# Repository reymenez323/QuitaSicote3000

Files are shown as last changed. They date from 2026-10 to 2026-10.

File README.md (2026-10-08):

# QuitaSicote3000

Equipo doméstico que elimina el mal olor del calzado con aire caliente forzado. Se controla sólo desde la pantalla táctil y tiene una capa de seguridad independiente (SIS).

Repositorio: https://github.com/reymenez323/QuitaSicote3000

**Empieza por [docs/PLAN-MAESTRO.md](docs/PLAN-MAESTRO.md)**: plan completo de electrónica y firmware.

**¿Vas a armar el equipo?** Sigue la [guía de conexión paso a paso](docs/guia-de-conexion/README.md) (incluye el diagrama de Fritzing en alta resolución).

> **Regla de máxima prioridad**: el **control** es el **ESP32 DevKit V1 de control** y el **SIS** es el **ESP32 Dev Kit**, estrictamente en todo el proyecto ([ADR-0012](docs/decisiones/ADR-0012-regla-mega-control-nano-sis.md)).
> **Hardware**: sólo módulos y dispositivos; sin optoacopladores, convertidores de nivel ni fusibles ([ADR-0013](docs/decisiones/ADR-0013-solo-modulos-y-dispositivos.md)).

## Nodos

| Nodo | Placa | Rol | Carpeta |
|---|---|---|---|
| Control | ESP32 DevKit V1 de control | Ciclo, sensores, SSR del PTC y ventiladores | [firmware/control](firmware/control/) |
| SIS | ESP32 Dev Kit | Seguridad: puede cortar el calentador sin pedir permiso | [firmware/sis](firmware/sis/) |
| HMI | ESP32-32E con pantalla 3.2" | Interfaz táctil; sólo comunicación | [firmware/hmi](firmware/hmi/) |

Los tres trabajan a 3,3 V y se conectan entre sí directamente.

## Estructura

```
QuitaSicote3000/
├─ docs/
│  ├─ PLAN-MAESTRO.md            Plan completo de implementación (electrónica + firmware). Empieza aquí
│  ├─ pinout/                    Pinout de cada controlador: control-esp32.md, sis-esp32.md, esp32-hmi.md
│  ├─ guia-de-conexion/          Guía paso a paso para conectar todo (con el diagrama de Fritzing por zonas)
│  ├─ requisitos.md              Qué debe hacer el sistema y parámetros provisionales
│  ├─ arquitectura.md            Nodos, reparto de responsabilidades, principios
│  ├─ maquina-de-estados.md      Ciclo de tratamiento (control)
│  ├─ perfiles-de-tratamiento.md Calzado × intensidad × duración
│  ├─ comunicacion.md            Enlaces UART y mensajes
│  ├─ seguridad-sis.md           Funciones de seguridad y su validación
│  └─ decisiones/                ADRs y decisiones abiertas
├─ hardware/
│  └─ fritzing/                  Diagrama de conexiones (.fzz editable y PNG de alta resolución)
└─ firmware/
   ├─ control/                   Proyecto PlatformIO del ESP32 DevKit V1 de control
   ├─ sis/                       Proyecto PlatformIO del ESP32 Dev Kit
   ├─ hmi/                       Proyecto PlatformIO del ESP32-32E (LVGL) + PLAN.md
   └─ compartido/qs_protocol.h   Contrato común entre nodos
```

## Convenciones

- Documentación y comentarios en español; identificadores de código en inglés.
- PlatformIO con Arduino-ESP32, un proyecto por nodo.
- Decisiones de diseño como ADR en [docs/decisiones](docs/decisiones/README.md).

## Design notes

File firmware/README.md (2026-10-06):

# Firmware

> Regla de máxima prioridad: **el control y el SIS corren en dos ESP32 DevKit V1 distintos** ([ADR-0012](../docs/decisiones/ADR-0012-regla-mega-control-nano-sis.md)).

Tres proyectos PlatformIO (framework Arduino-ESP32). **Toda la lógica corre en tareas de FreeRTOS** y cada proyecto cabe en muy pocos archivos, pensados para leerse de arriba abajo.

```
firmware/
├─ compartido/
│  └─ qs_protocol.h     El "contrato": identificadores, mensajes y tramas. Lo incluyen los tres.
├─ sis/                 ESP32 DevKit V1 n.º 2 — sólo seguridad
│  └─ src/  config.h (pines y umbrales) · main.cpp
├─ control/             ESP32 DevKit V1 n.º 1 — sólo control
│  └─ src/  config.h (pines, parámetros y perfiles) · sensors.h · main.cpp
└─ hmi/                 ESP32-32E con pantalla 3.2" — sólo interfaz
   ├─ include/lv_conf.h (configuración de LVGL)
   └─ src/  display.h (pines y pantalla) · ui.h · ui.cpp (pantallas) · main.cpp
```

## Tareas de cada nodo

| Nodo | Tarea | Periodo | Qué hace |
|---|---|---|---|
| SIS | `taskSafety` | 10 ms | Puerta → funciones de seguridad → relés RL1, RL3, RL4. Vigilada por el watchdog (1 s) |
| SIS | `taskLink` | 10 ms | Habla con el control; guarda en memoria no volátil |
| Control | `taskCycle` | 10 ms | Puerta → máquina de estados → SSR1 y ventiladores. Vigilada por el watchdog (2 s) |
| Control | `taskSensors` | 250 ms | TC1 y TC2 alternados; cada segundo, humedad y olor |
| Control | `taskSisLink` | 10 ms | Recibe `HB_SIS`; envía `HB_CTRL`, rearmes y servicio |
| Control | `taskHmiLink` | 10 ms | Recibe las solicitudes de la pantalla; envía `STATUS` |
| Control | `taskConsole` | 100 ms | Comandos por USB y registro CSV |
| HMI | `taskUi` | 5 ms | LVGL: dibuja y lee el táctil |
| HMI | `taskLink` | 10 ms | Recibe `STATUS`; envía el latido y las solicitudes |

En cada nodo, las tareas comparten unas pocas variables globales protegidas por **un mutex** (clase `Lock`). Donde una tarea le encarga algo a otra se usa **una cola** (avisos del SIS, botones del HMI).

## Compilar y cargar

Desde la carpeta de cada proyecto (`sis`, `control` o `hmi`):

```bash
pio run -t upload
```

```bash
pio device monitor
```

Si `pio` no está en el PATH: `%USERPROFILE%\.platformio\penv\Scripts\pio.exe`.

Las dos placas DevKit V1 son iguales: **etiquétalas** ("CONTROL" y "SIS") y carga en cada una su firmware.

## Estado

Los tres proyectos compilan. **Nada se ha probado todavía en hardware.** No hay pruebas automáticas: la validación es en banco, siguiendo [docs/seguridad-sis.md](../docs/seguridad-sis.md#validación) (inyección de fallas V-01…V-13). Repetirla tras cada cambio del SIS.

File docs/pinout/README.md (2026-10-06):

# Pinout por controlador

> Regla de máxima prioridad: **control y SIS en dos ESP32 DevKit V1 distintos** ([ADR-0012](../decisiones/ADR-0012-regla-mega-control-nano-sis.md)). Sólo módulos y dispositivos ([ADR-0013](../decisiones/ADR-0013-solo-modulos-y-dispositivos.md)).

Un documento independiente por cada controlador:

| Controlador | Nodo | Qué maneja | Documento |
|---|---|---|---|
| ESP32 DevKit V1 n.º 1 | **Control** | SSR1 (PTC), SSR2 (FAN_C), RL2 (apagar FAN_P), TC1, TC2, SHT31, SGP40, puerta | [control-esp32.md](control-esp32.md) |
| ESP32 DevKit V1 n.º 2 | **SIS** | RL1 (permiso del PTC), RL3 (veto del apagado de FAN_P), RL4 (forzado de FAN_C), puerta | [sis-esp32.md](sis-esp32.md) |
| ESP32-32E (pantalla 3.2") | HMI | Nada del proceso: pantalla, táctil y enlace | [esp32-hmi.md](esp32-hmi.md) |

Los tres trabajan a **3,3 V**: todos los cables entre ellos son **directos**. Contexto eléctrico completo: [PLAN-MAESTRO §5](../PLAN-MAESTRO.md#5-electrónica).
Las dos placas son del mismo modelo: **etiquetarlas** ("CONTROL" y "SIS"). Usan los mismos números de pin para la puerta, las salidas, el SPI y el UART entre ellas.

## Cables entre controladores

| Señal | Desde | Hacia |
|---|---|---|
| UART control → SIS | Control GPIO17 (TX2) | SIS GPIO16 (RX2) |
| UART SIS → control | SIS GPIO17 (TX2) | Control GPIO16 (RX2) |
| UART control → HMI | Control GPIO4 (TX1) | HMI IO32 (RX2) |
| UART HMI → control | HMI IO25 (TX2) | Control GPIO35 (RX1) |
| Puerta NA (compartida) | SW1.NA | Control GPIO32 y SIS GPIO32 |
| Puerta NC (compartida) | SW1.NC | Control GPIO33 y SIS GPIO33 |
| GND común | GND de las tres placas | Estrella de tierra |

## Combinación por contactos (no hay cable entre controladores)

| Ventilador | Control | SIS | Combinación |
|---|---|---|---|
| FAN_P | RL2 (GPIO27) | RL3 (GPIO26) | Contactos NC en paralelo: se apaga sólo si ambos están energizados |
| FAN_C | SSR2 (GPIO26) | RL4 (GPIO27) | Contacto NA en paralelo con SSR2: se enciende si cualquiera lo activa |

## Polaridades que el firmware debe respetar

| Señal | Controlador | ALTO significa |
|---|---|---|
| `PIN_SSR1` | Control | Calentar |
| `PIN_FAN_C` | Control | Encender ventilador de circulación |
| `PIN_FAN_P_OFF` | Control | **Pedir apagado** del ventilador del PTC |
| `PIN_PTC_PERMIT` | SIS | PTC permitido (RL1 cerrado) |
| `PIN_FAN_P_OFF_PERMIT` | SIS | **Permitir** apagar el ventilador del PTC |
| `PIN_FAN_C_FORCE` | SIS | Forzar ventilador de circulación |
| Puerta NA / NC | Control y SIS | Contacto abierto. Puerta cerrada = NA BAJO + NC ALTO |
| LED RGB del HMI | HMI | **Apagado** (ánodo común) |

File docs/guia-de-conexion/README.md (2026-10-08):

# Guía de conexión

Sigue los pasos **en orden**, con la fuente **desenchufada**. Marca cada ☐ al terminar.
Si la guía y los [pinout](../pinout/README.md) no coinciden, mandan los pinout.

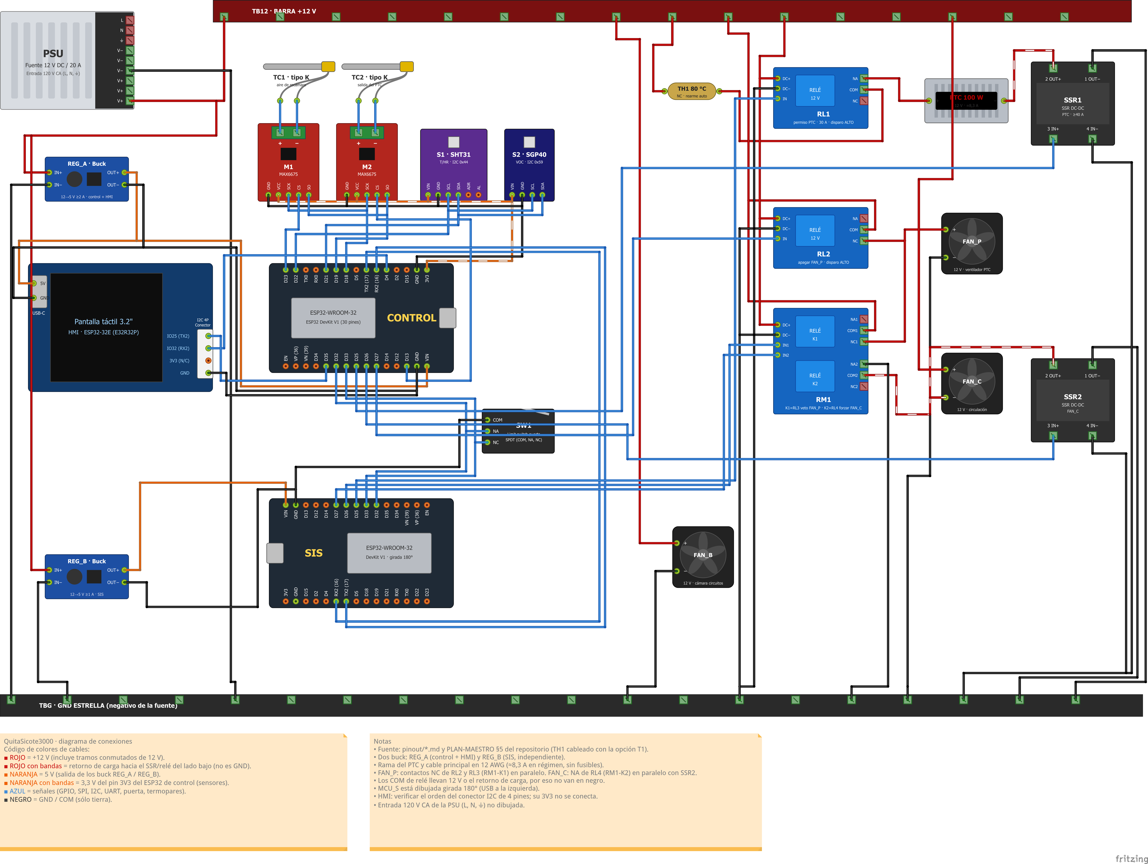
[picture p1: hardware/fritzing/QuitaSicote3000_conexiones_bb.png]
Diagrama completo


Diagrama completo en alta resolución (7740 × 5829 px): [PNG](../../hardware/fritzing/QuitaSicote3000_conexiones_bb.png) · [Fritzing editable](../../hardware/fritzing/QuitaSicote3000_conexiones.fzz).
Pinouts de las placas y módulos: [ver tablas](#pinouts).
Recortes a escala completa: [1 Fuente](zona1-fuente-y-reguladores.png) · [2 Control y sensores](zona2-control-y-sensores.png) · [3 SIS y puerta](zona3-sis-y-puerta.png) · [4 Cargas](zona4-cargas.png).

| Color de cable | Significa |
|---|---|
| 🟥 Rojo | +12 V |
| 🟥 Rojo con bandas | Retorno de carga (lleva 12 V, **no** es tierra) |
| 🟧 Naranja | 5 V |
| 🟦 Azul | Señal de 3,3 V |
| ⬛ Negro | GND |

---

## ⚠️ Antes de empezar

- ☐ **Etiqueta las dos placas ESP32 como CONTROL y SIS.** Son idénticas; si se confunden, el equipo no es seguro.
- **Nunca pongas 12 V ni 5 V en un pin de señal (azul).** Destruye la placa.
- **Sin fusibles:** cable de **12 AWG** en la rama del calefactor; cables finos cortos y sujetos.
- Los **120 V de la fuente** no están en el diagrama: se conectan **al final**, con bornes tapados. Sin experiencia, que lo haga un electricista.
- **No conectes USB a una placa mientras su regulador de 5 V esté conectado.**
- Necesitas un **multímetro** y los firmwares cargados ([firmware/](../../firmware/README.md)): cárgalos **antes** de cablear, cada placa sola por USB.
- En el diagrama el SIS está **girado 180°**: guíate por la etiqueta del pin (`D25`, `GND`…), no por la posición.

---

## Paso 1 — Barras de 12 V y GND  📷 [zona 1](zona1-fuente-y-reguladores.png)

| Desde | Hacia | Cable |
|---|---|---|
| Fuente `V+` | Barra **TB12** | Rojo, 12 AWG |
| Fuente `V−` | Barra **TBG** (GND) | Negro, 12 AWG |

☐ Multímetro en continuidad: TB12 ↔ TBG **no** debe pitar.

## Paso 2 — Reguladores de 5 V  📷 [zona 1](zona1-fuente-y-reguladores.png)

| Desde | Hacia |
|---|---|
| TB12 | REG_A `IN+` y REG_B `IN+` |
| TBG | REG_A `IN−` y REG_B `IN−` (un cable cada uno) |

☐ Con la fuente encendida y **nada** en las salidas, gira el tornillo de cada regulador hasta medir **5,0–5,1 V** entre `OUT+` y `OUT−`. Apaga y desenchufa.

## Paso 3 — Sensores de CONTROL  📷 [zona 2](zona2-control-y-sensores.png)

| Desde | Hacia | Cable |
|---|---|---|
| CONTROL `3V3` | M1 `VCC`, M2 `VCC`, S1 `VIN`, S2 `VIN` | Naranja |
| CONTROL `GND` | M1 `GND`, M2 `GND`, S1 `GND`, S2 `GND` | Negro |
| CONTROL `D18` | M1 `SCK` y M2 `SCK` | Azul |
| CONTROL `D19` | M1 `SO` y M2 `SO` | Azul |
| CONTROL `D23` | M1 `CS` | Azul |
| CONTROL `D13` | M2 `CS` | Azul |
| CONTROL `D21` | S1 `SDA` y S2 `SDA` | Azul |
| CONTROL `D22` | S1 `SCL` y S2 `SCL` | Azul |
| Termopar TC1 | M1 `+` / `−` | |
| Termopar TC2 | M2 `+` / `−` | |

- Sensores a **3,3 V, no a 5 V**. `ADR` y `AL` del SHT31: sin conectar.
- Termopar: hilo positivo a `+` (en ANSI tipo K suele ser el amarillo). Si al calentar la lectura baja, están invertidos.

## Paso 4 — Puerta (SW1)  📷 [zona 3](zona3-sis-y-puerta.png)

| Desde | Hacia |
|---|---|
| SW1 `COM` | TBG |
| SW1 `NA` | CONTROL `D32` **y** SIS `D32` |
| SW1 `NC` | CONTROL `D33` **y** SIS `D33` |

El cable de `NA` (y el de `NC`) se divide en dos: uno a cada placa. Sin resistencias externas.

## Paso 5 — Alimentación de las placas

| Desde | Hacia | Cable |
|---|---|---|
| REG_A `OUT+` | CONTROL `VIN` | Naranja |
| REG_A `OUT−` | CONTROL `GND` | Negro |
| REG_A `OUT+` | Pantalla USB-C `5V` | Naranja |
| REG_A `OUT−` | Pantalla USB-C `GND` | Negro |
| REG_B `OUT+` | SIS `VIN` | Naranja |
| REG_B `OUT−` | SIS `GND` | Negro |

## Paso 6 — Enlaces entre placas  📷 [zona 1](zona1-fuente-y-reguladores.png) · [2](zona2-control-y-sensores.png) · [3](zona3-sis-y-puerta.png)

**TX va al RX del otro** (cruzados). Todos los GND de las placas, juntos.

| Desde | Hacia |
|---|---|
| CONTROL `D17` (TX2) | SIS `D16` (RX2) |
| SIS `D17` (TX2) | CONTROL `D16` (RX2) |
| CONTROL `D4` | Pantalla `IO32` |
| Pantalla `IO25` | CONTROL `D35` |
| Pantalla `GND` | CONTROL `GND` |

Los pines `IO25`, `IO32` y `GND` están en el **conector pequeño de 4 pines "I2C"** de la pantalla. **No conectes su `3V3`.**
☐ Identifica cada pin de ese conector con el multímetro antes de conectar (el orden no está confirmado).

## Paso 7 — Módulos de relé y SSR: 12 V y señales  📷 [zona 4](zona4-cargas.png)

| Módulo | Conexión | Hacia |
|---|---|---|
| RL1, RL2, RM1 | `DC+` | TB12 |
| RL1, RL2, RM1 | `DC−` | TBG |
| SSR1 | `4 IN−` | TBG |
| SSR2 | `4 IN−` | TBG |
| SSR1 | `3 IN+` | CONTROL `D25` |
| SSR2 | `3 IN+` | CONTROL `D26` |
| RL2 | `IN` | CONTROL `D27` |
| RL1 | `IN` | SIS `D25` |
| RM1 | `IN1` | SIS `D26` |
| RM1 | `IN2` | SIS `D27` |

RM1 con bobina de 12 V: confírmalo en la etiqueta de tu módulo (algunos son de 5 V).

## Paso 8 — Ventiladores  📷 [zona 4](zona4-cargas.png)

| Desde | Hacia | Cable |
|---|---|---|
| TB12 | FAN_B `+` | Rojo |
| FAN_B `−` | TBG | Negro |
| TB12 | RL2 `COM` | Rojo |
| TB12 | RM1 `COM1` | Rojo |
| RL2 `NC` | FAN_P `+` | Rojo |
| RM1 `NC1` | FAN_P `+` (mismo punto) | Rojo |
| FAN_P `−` | TBG | Negro |
| TB12 | FAN_C `+` | Rojo |
| FAN_C `−` | SSR2 `2 OUT+` | Rojo con bandas |
| FAN_C `−` | RM1 `COM2` (mismo punto) | Rojo con bandas |
| SSR2 `1 OUT−` | TBG | Negro |
| RM1 `NA2` | TBG | Negro |

## Paso 9 — Calefactor PTC  📷 [zona 4](zona4-cargas.png)

> ⚠️ **Último paso. Todo en 12 AWG con terminales bien apretados** (≈ 8,3 A). Para las primeras pruebas **usa una lámpara de 12 V / 21 W en lugar del PTC.**

`TB12 → TH1 → RL1 (COM→NA) → PTC → SSR1 → TBG`

| Desde | Hacia |
|---|---|
| TB12 | TH1 (un cable) |
| TH1 (otro cable) | RL1 `COM` |
| RL1 `NA` | PTC `+` (o lámpara) |
| PTC `−` (o lámpara) | SSR1 `2 OUT+` |
| SSR1 `1 OUT−` | TBG |

`RL1 NC` queda sin conectar. TH1 va en el aire caliente, **sin tocar las aletas** del PTC. SSR1 con disipador.

---

## Pinouts

Todos los pines de señal son de **3,3 V**. "Etiqueta" es lo que está impreso en la placa. Detalle completo: [control](../pinout/control-esp32.md) · [SIS](../pinout/sis-esp32.md) · [pantalla](../pinout/esp32-hmi.md).

### CONTROL (ESP32 DevKit V1)

| Etiqueta | GPIO | Dir. | Señal | Va a | ALTO / BAJO significa |
|---|---|---|---|---|---|
| `D25` | 25 | Salida | Calentar | SSR1 `3 IN+` | ALTO = calentar |
| `D26` | 26 | Salida | Ventilador de circulación | SSR2 `3 IN+` | ALTO = encender |
| `D27` | 27 | Salida | Pedir apagar FAN_P | RL2 `IN` | ALTO = pedir apagado |
| `D32` | 32 | Entrada | Puerta NA | SW1 `NA` (y SIS `D32`) | BAJO = contacto cerrado |
| `D33` | 33 | Entrada | Puerta NC | SW1 `NC` (y SIS `D33`) | BAJO = contacto cerrado |
| `D21` | 21 | E/S | I2C SDA | S1 `SDA`, S2 `SDA` | — |
| `D22` | 22 | Salida | I2C SCL | S1 `SCL`, S2 `SCL` | — |
| `D18` | 18 | Salida | SPI SCK | M1 `SCK`, M2 `SCK` | — |
| `D19` | 19 | Entrada | SPI MISO | M1 `SO`, M2 `SO` | — |
| `D23` | 23 | Salida | CS de TC1 | M1 `CS` | BAJO = seleccionado |
| `D13` | 13 | Salida | CS de TC2 | M2 `CS` | BAJO = seleccionado |
| `D17` (`TX2`) | 17 | Salida | Datos → SIS | SIS `D16` | UART 115200 |
| `D16` (`RX2`) | 16 | Entrada | Datos ← SIS | SIS `D17` | UART 115200 |
| `D4` | 4 | Salida | Datos → pantalla | Pantalla `IO32` | UART 115200 |
| `D35` | 35 | Entrada | Datos ← pantalla | Pantalla `IO25` | UART 115200 |
| `3V3` | — | Salida | 3,3 V | M1, M2, S1, S2 (`VCC`/`VIN`) | — |
| `VIN` | — | Entrada | 5 V | REG_A `OUT+` | — |
| `GND` | — | — | Tierra | TBG y todos los GND | — |

No uses otros pines: `0, 2, 5, 12, 14, 15` son de arranque y `1, 3, 6–11` son de USB y memoria.

### SIS (ESP32 DevKit V1)

| Etiqueta | GPIO | Dir. | Señal | Va a | ALTO / BAJO significa |
|---|---|---|---|---|---|
| `D25` | 25 | Salida | Permiso para calentar | RL1 `IN` | ALTO = permitido |
| `D26` | 26 | Salida | Permitir apagar FAN_P | RM1 `IN1` (RL3) | ALTO = se permite apagar |
| `D27` | 27 | Salida | Forzar FAN_C | RM1 `IN2` (RL4) | ALTO = forzar encendido |
| `D32` | 32 | Entrada | Puerta NA | SW1 `NA` (y CONTROL `D32`) | BAJO = contacto cerrado |
| `D33` | 33 | Entrada | Puerta NC | SW1 `NC` (y CONTROL `D33`) | BAJO = contacto cerrado |
| `D17` (`TX2`) | 17 | Salida | Datos → CONTROL | CONTROL `D16` | UART 115200 |
| `D16` (`RX2`) | 16 | Entrada | Datos ← CONTROL | CONTROL `D17` | UART 115200 |
| `VIN` | — | Entrada | 5 V | REG_B `OUT+` | — |
| `GND` | — | — | Tierra | TBG | — |

El SIS no tiene sensores ni termopares. Pines libres: `13, 18, 19, 21, 22, 23` (no conectar nada).

### Pantalla HMI (ESP32-32E)

Solo se usan estas conexiones externas; el resto de la placa ya viene cableado.

| Conector | Pin | Dir. | Señal | Va a |
|---|---|---|---|---|
| I2C (4 pines, 1,25 mm) | `IO25` | Salida | Datos → CONTROL (UART2 TX) | CONTROL `D35` |
| I2C (4 pines, 1,25 mm) | `IO32` | Entrada | Datos ← CONTROL (UART2 RX) | CONTROL `D4` |
| I2C (4 pines, 1,25 mm) | `GND` | — | Tierra | CONTROL `GND` |
| I2C (4 pines, 1,25 mm) | `3V3` | — | **No conectar** | — |
| USB-C | `5V` | Entrada | Alimentación | REG_A `OUT+` |
| USB-C | `GND` | — | Tierra | REG_A `OUT−` |

### Módulos (terminales)

| Módulo | Terminales y a dónde van |
|---|---|
| **M1 / M2** (MAX6675) | `VCC` ← 3V3 · `GND` · `SCK` ← D18 · `SO` → D19 · `CS` ← D23 (M1) o D13 (M2) · `+`/`−` ← termopar |
| **S1** (SHT31) | `VIN` ← 3V3 · `GND` · `SDA` ← D21 · `SCL` ← D22 · `ADR`, `AL` sin conectar |
| **S2** (SGP40) | `VIN` ← 3V3 · `GND` · `SDA` ← D21 · `SCL` ← D22 |
| **SW1** | `COM` → GND · `NA` → D32 (ambas placas) · `NC` → D33 (ambas placas) |
| **RL1** (30 A) | `DC+` ← 12 V · `DC−` → GND · `IN` ← SIS D25 · `COM` ← TH1 · `NA` → PTC `+` · `NC` sin conectar |
| **RL2** | `DC+` ← 12 V · `DC−` → GND · `IN` ← CONTROL D27 · `COM` ← 12 V · `NC` → FAN_P `+` · `NA` sin conectar |
| **RM1** (2 relés) | `DC+` ← 12 V · `DC−` → GND · `IN1` ← SIS D26 · `IN2` ← SIS D27 · `COM1` ← 12 V · `NC1` → FAN_P `+` · `COM2` ↔ FAN_C `−` · `NA2` → GND · `NA1`, `NC2` sin conectar |
| **SSR1** | `3 IN+` ← CONTROL D25 · `4 IN−` → GND · `2 OUT+` ← PTC `−` · `1 OUT−` → GND |
| **SSR2** | `3 IN+` ← CONTROL D26 · `4 IN−` → GND · `2 OUT+` ← FAN_C `−` · `1 OUT−` → GND |
| **REG_A / REG_B** | `IN+` ← 12 V · `IN−` → GND · `OUT+` → 5 V a su placa · `OUT−` → GND de su placa |

---

## Revisión (fuente desenchufada)

☐ TB12 ↔ TBG: **no** pita.
☐ `3V3` ↔ `GND` de CONTROL: **no** pita.
☐ Salidas `OUT+` ↔ `OUT−` de REG_A y REG_B: **no** pita.
☐ `D25`/`D26`/`D27` de CONTROL y SIS ↔ TB12: **no** pita.
☐ Todos los GND ↔ TBG: **sí** pita.
☐ Terminales gruesos apretados (tira de cada cable).

## Primer encendido

1. ☐ **Solo fuente y reguladores** (sin cables a las placas): TB12 = 12 V, reguladores = 5,0–5,1 V. FAN_B y FAN_P giran.
2. ☐ **Conecta las placas.** La pantalla enciende (la primera vez: toca las 4 esquinas para calibrar).
   - Punto arriba a la derecha: 🟢 verde = hay comunicación · 🔴 rojo = revisa el paso 6.
   - Abre y cierra la puerta: la pantalla debe cambiar entre "Puerta abierta" y "Puerta cerrada" (paso 4).
   - En reposo ningún relé hace clic y la lámpara está apagada.
3. ☐ **Ciclo de prueba con la lámpara**, duración corta: la lámpara se enciende y apaga, FAN_C gira. **Abre la puerta: la lámpara se apaga al instante.**
4. ☐ **Con el PTC real** (solo si lo anterior funcionó): con supervisión, sobre superficie no inflamable, sin calzado y con extintor cerca. Tras unos minutos revisa que ningún terminal grueso esté caliente.

## Si algo falla

| Síntoma | Revisa |
|---|---|
| Pantalla apagada | 5 V y polaridad en el USB-C de la pantalla |
| Punto rojo | Paso 6: TX↔RX cruzados, GND común |
| "Revisa la puerta" / puerta al revés | Paso 4: `NA` y `NC` |
| Falla de sensor de temperatura | Paso 3: polaridad del termopar, `SCK`/`SO`/`CS` |
| Humedad u olor "--" | Paso 3: `SDA`/`SCL`, alimentación a 3,3 V |
| No calienta | RL1 debe hacer clic al iniciar; `D25` de SIS y CONTROL |
| Lámpara encendida sin ciclo | **Desenchufa.** SSR1 en corto o `D25` mal |
| FAN_P no gira al encender | Paso 8: `COM` a 12 V y `NC` a FAN_P |
| Algo huele o se calienta | **Desenchufa** y busca el cable |

## Por verificar con las piezas reales

- Orden de los 4 pines del conector de la pantalla (paso 6).
- Que RL1, RL2, RM1, SSR1 y SSR2 **se activen con 3,3 V** y **no** con la entrada al aire (pruébalos antes de montarlos).
- Que las placas aíslen el USB del pin `VIN` (si no, nunca USB y regulador a la vez).
- Que RL1 y TH1 aguanten ≈ 8,3 A en continua, y que la fuente soporte el arranque del PTC.
- El equipo tiene **dos** termopares (TC1 y TC2, ambos en CONTROL); el SIS no tiene.

Más detalle: [pinout](../pinout/README.md) · [comunicación](../comunicacion.md) · [plan maestro §5](../PLAN-MAESTRO.md#5-electrónica).

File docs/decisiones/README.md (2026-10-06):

# Decisiones de diseño (ADR)

> **Regla de máxima prioridad ([ADR-0012](ADR-0012-regla-mega-control-nano-sis.md))**: el control es el **ESP32 DevKit V1 de control** y el SIS es el **ESP32 Dev Kit**. Ninguna función se mueve de uno a otro.
> **Preferencia de hardware ([ADR-0013](ADR-0013-solo-modulos-y-dispositivos.md))**: sólo módulos y dispositivos; sin optoacopladores, convertidores de nivel ni fusibles.

| ID | Decisión | Estado |
|---|---|---|
| [ADR-0012](ADR-0012-regla-mega-control-nano-sis.md) | **Control y SIS en controladores separados, estrictamente** (ESP32 DevKit V1 de control / ESP32 Dev Kit) | **Aceptada, prioritaria** |
| [ADR-0013](ADR-0013-solo-modulos-y-dispositivos.md) | Sólo módulos y dispositivos; lógica con contactos de relé | Aceptada |
| [ADR-0001](ADR-0001-separacion-control-sis.md) | Control y SIS en MCU independientes | Aceptada |
| [ADR-0002](ADR-0002-mcu-del-sis.md) | Control en ESP32 DevKit V1 de control, SIS en ESP32 Dev Kit (antes Mega y Nano) | Aceptada |
| ADR-0003 | (Retirada; reemplazada por la ADR-0010) | — |
| [ADR-0004](ADR-0004-asignacion-termopares.md) | TC1/TC2 al control, el SIS sin termopar | Aceptada |
| [ADR-0005](ADR-0005-hmi-esp32.md) | Pantalla ESP32-32E como nodo HMI sólo de comunicación | Aceptada |
| [ADR-0006](ADR-0006-producto-domestico-sin-paro-fisico.md) | Producto doméstico, sin paro físico | Aceptada |
| [ADR-0007](ADR-0007-perfiles-en-el-control.md) | Perfiles en el control; SIS con límite único | Propuesta |
| [ADR-0008](ADR-0008-termostato-rearme-automatico.md) | Termostato bimetálico: enclavado y bloqueo tras 2 eventos; cableado T1/T2 | Aceptada; cableado pendiente (A-11) |
| [ADR-0009](ADR-0009-ventilador-ptc-con-rele.md) | Ventilador del PTC: relé del control y relé de veto del SIS (NC en paralelo) | Aceptada |
| [ADR-0010](ADR-0010-permiso-ptc-modulo-rele.md) | Permiso del PTC con un módulo de relé en serie | Aceptada |
| [ADR-0011](ADR-0011-sin-componentes-auxiliares.md) | Sin componentes auxiliares (versión que movía los ventiladores al SIS) | **Revocada** |

## Decisiones abiertas

Detalle, opciones y recomendación en [PLAN-MAESTRO §4.2](../PLAN-MAESTRO.md#42-abiertas):

| ID | Pregunta |
|---|---|
| **A-11** | Dónde cablear el termostato bimetálico: en serie con el PTC (T1, recomendado) o en la señal del SIS hacia RL1 (T2, se puede leer) |
| **A-12** | ¿Módulo sensor de voltaje para que el SIS lea los nodos de 12 V? |
| A-4 | Pérdida del heartbeat del control: ¿disparo enclavado o sólo retirar el permiso? |
| A-5 | Procedimiento de servicio tras el bloqueo |
| A-6 | ¿VOC/HR como criterio de fin anticipado? |
| A-7 | Registro de ciclos: USB del control o SD del HMI |
| A-8 | Nombres definitivos de los 4 calzados |

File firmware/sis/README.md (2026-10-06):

# Firmware del SIS (ESP32 DevKit V1 n.º 2)

> **Sólo seguridad.** Ninguna función de control se implementa aquí ([ADR-0012](../../docs/decisiones/ADR-0012-regla-mega-control-nano-sis.md)).

Especificación: [PLAN-MAESTRO §7](../../docs/PLAN-MAESTRO.md#7-firmware-del-sis-esp32-dev-kit) y [seguridad-sis.md](../../docs/seguridad-sis.md). Pines: [docs/pinout/sis-esp32.md](../../docs/pinout/sis-esp32.md).

## Archivos

| Archivo | Contenido |
|---|---|
| [src/config.h](src/config.h) | Pines y **todos** los umbrales. Ninguno se recibe por la comunicación |
| [src/main.cpp](src/main.cpp) | Todo lo demás, en este orden: estado compartido → memoria → disparo, rearme y servicio → funciones de seguridad → las dos tareas → arranque |

## Cómo funciona

- `taskSafety` (10 ms) lee la puerta, evalúa las funciones de seguridad y escribe los tres relés: **RL1** (permiso del PTC), **RL3** (permiso de apagar el ventilador del PTC) y **RL4** (forzar el ventilador de circulación).
- `taskLink` recibe `HB_CTRL`, `REQ_RESET` y `REQ_SERVICE`; envía `HB_SIS` y los avisos; guarda en NVS para que la tarea de seguridad nunca espere a la flash.
- Lo que llega del control **sólo puede restringir**: `heat_request` puede quitar el permiso, nunca concederlo por sí solo.

## Estados

```
ARRANQUE ──autotest correcto──► OK ──disparo──► DISPARADO ──rearme aceptado──► OK
                                                    │
                                     2.º evento térmico ──► BLOQUEADO ──servicio──► DISPARADO
```

En ARRANQUE, DISPARADO y BLOQUEADO el PTC no tiene permiso. Los eventos térmicos (sólo SIF-07) se cuentan y se guardan: sobreviven a un corte de energía.

LED de la placa: fijo = OK · parpadeo lento = arrancando · rápido = disparado · destello corto = bloqueado.

## Decisiones abiertas aplicadas (cambiar si se decide otra cosa)

- **Sin termopar** ([ADR-0004](../../docs/decisiones/ADR-0004-asignacion-termopares.md)): el SIS sólo tiene SIF-02, SIF-06 y SIF-07. "Frío" = 10 min sin permiso del PTC.
- **A-11 → T1**: el termostato va en serie con el PTC y el SIS no lo lee (sin TC3 tampoco puede inferirlo).
- **A-4**: perder el latido del control con el permiso concedido es un disparo enclavado (SIF-06).
- **A-5**: desbloqueo = comando `servicio desbloquear` en la consola del control + abrir y cerrar la puerta 3 veces en 30 s.

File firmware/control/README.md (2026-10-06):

# Firmware de control (ESP32 DevKit V1 n.º 1)

> **Sólo control.** Ninguna función de seguridad se implementa aquí ([ADR-0012](../../docs/decisiones/ADR-0012-regla-mega-control-nano-sis.md)). Sus límites son de proceso (capa 1).

Especificación: [PLAN-MAESTRO §8](../../docs/PLAN-MAESTRO.md#8-firmware-de-control-esp32-s3). Pines: [docs/pinout/control-esp32.md](../../docs/pinout/control-esp32.md).

## Archivos

| Archivo | Contenido |
|---|---|
| [src/config.h](src/config.h) | Pines, parámetros y la **tabla de perfiles** (temperaturas y duraciones) |
| [src/sensors.h](src/sensors.h) | Lectura de MAX6675, SHT31 y SGP40 |
| [src/main.cpp](src/main.cpp) | Todo lo demás: estado compartido → fallas → solicitudes del HMI → máquina de estados → calefactor y ventiladores → las cinco tareas → arranque |

## Cómo funciona

- `taskCycle` (10 ms) lee la puerta, avanza la máquina de estados y escribe **SSR1** (PTC), **SSR2** (ventilador de circulación) y **RL2** (pedir apagar el ventilador del PTC).
- `taskSensors` lee TC1 y TC2 alternados cada 250 ms y, una vez por segundo, el SHT31 y el SGP40 (con el algoritmo de índice de olor de Sensirion).
- `taskSisLink` y `taskHmiLink` atienden los dos enlaces serie.
- `taskConsole` atiende el USB.

Reglas que el código respeta:

- SSR1 sólo conduce calentando, con la puerta cerrada **y** con el permiso del SIS concedido.
- Abrir la puerta pausa el ciclo; cerrarla no lo reanuda: hace falta "Reanudar".
- Una pausa de más de 5 min, o perder la pantalla más de 10 s, cancela el ciclo.
- Tras un reinicio o un corte de energía siempre se empieza en AUTOTEST: un ciclo nunca se reanuda solo.
- El ventilador del PTC nunca se pide apagar calentando ni con el equipo caliente.

## Consola (USB, 115200)

| Comando | Efecto |
|---|---|
| `status` | Una línea con el estado actual |
| `log on` / `log off` | Registro CSV permanente (durante un ciclo se registra siempre, una línea por segundo) |
| `servicio desbloquear` | Pide al SIS abrir la ventana de desbloqueo |

## Pendiente

- Regulación en etapa 1 (histéresis). El PI con ventana proporcional queda para la fase F9.
- Valores de los perfiles y límites de TC2: se ajustan con los ensayos (F7 y F9).

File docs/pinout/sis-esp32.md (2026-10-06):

# Pinout — ESP32 Dev Kit (nodo SIS)

> Regla de máxima prioridad: este controlador hace **sólo seguridad** ([ADR-0012](../decisiones/ADR-0012-regla-mega-control-nano-sis.md)). No maneja ventiladores: sólo **veta** el apagado de FAN_P (RL3) y **fuerza** FAN_C (RL4) con sus propios relés.

Placa: **ESP32 DevKit V1** (DOIT, ESP32-WROOM-32, 30 pines) [CONFIRMADO, 2026-10-06], el mismo modelo que la del control: **etiquetar las dos placas**. Lógica a **3,3 V**: ningún pin tolera 5 V.
Sólo módulos y dispositivos, sin componentes sueltos ([ADR-0013](../decisiones/ADR-0013-solo-modulos-y-dispositivos.md)). Estado: **[PROPUESTA]** salvo lo marcado.
Las constantes van en `firmware/sis/src/config.h`.

## 1. Alimentación y pines de sistema

| Pin de la placa | Conexión | Notas |
|---|---|---|
| **5V / VIN** | ← salida de **REG_B** (5V_B) | Regulador independiente del del control [CONFIRMADO]. Comprobar si la placa aísla el USB de este pin [VERIFICAR]; si no, no conectar el USB a la vez |
| **GND** | ← GND de REG_B → estrella de tierra | Común con el control |
| USB (UART0, GPIO1/3) | Programación y depuración | Wi-Fi y Bluetooth apagados en el firmware |

## 2. Pines usados

| GPIO | Dir. | Señal | Conecta a (componente.terminal) | Lógica | Constante |
|---|---|---|---|---|---|
| 32 | Entrada (pull-up interno) | Puerta NA | SW1.**NA** (la misma línea va al control GPIO32) | BAJO = contacto cerrado | `PIN_DOOR_NO` |
| 33 | Entrada (pull-up interno) | Puerta NC | SW1.**NC** (la misma línea va al control GPIO33) | BAJO = contacto cerrado | `PIN_DOOR_NC` |
| 25 | Salida | **Permiso del PTC** | **RL1.IN** (módulo de 30 A, disparo ALTO, contacto NA en serie con el PTC). Con la opción T2: GPIO25 → TH1 → RL1.IN | **ALTO = permitido** | `PIN_PTC_PERMIT` |
| 26 | Salida | Permiso de apagado de FAN_P | **RM1 canal 1 (RL3).IN**; contacto NC en paralelo con RL2 del control | **ALTO = se permite apagar** | `PIN_FAN_P_OFF_PERMIT` |
| 27 | Salida | Forzar FAN_C | **RM1 canal 2 (RL4).IN**; contacto NA en paralelo con la salida de SSR2 | ALTO = forzar encendido | `PIN_FAN_C_FORCE` |
| 16 | Entrada | UART2 RX ← control | Control **GPIO17 (TX2)** | UART 115200 8N1 | `PIN_CTRL_RX` |
| 17 | Salida | UART2 TX → control | Control **GPIO16 (RX2)** | UART | `PIN_CTRL_TX` |
| 4 | Entrada (pull-down interno) | Lectura del termostato | **Sólo con la opción T2**: lado de RL1.IN de TH1 | ALTO = termostato cerrado | `PIN_TH_SENSE` |
| 2 | Salida | LED de la placa | LED integrado | Estado / falla | `PIN_LED` |

SW1.COM va a GND. **El SIS no tiene termopar** ([ADR-0004](../decisiones/ADR-0004-asignacion-termopares.md)): no hay M3 ni SPI.

### Módulos de salida (conexión completa)

| Módulo | VCC | GND | IN | Contacto |
|---|---|---|---|---|
| RL1 (permiso del PTC, 30 A) | 12 V | GND común | GPIO25 (T1) o GPIO25 → TH1 (T2) | COM ← TH1 (T1) o 12 V (T2); **NA** → PTC(+) |
| RM1 canal 1 = RL3 | 12 V (o 5 V según el módulo) | GND común | GPIO26 | COM ← 12 V; **NC** → FAN_P(+) (en paralelo con RL2.NC) |
| RM1 canal 2 = RL4 | ídem | GND común | GPIO27 | COM ← FAN_C(−); **NA** → GND (en paralelo con la salida de SSR2) |

Disparo **ALTO** en los tres; deben activarse con 3,3 V y quedar desactivados con la entrada al aire [VERIFICAR en F3].

## 3. Pines que no se usan a propósito

| GPIO | Motivo |
|---|---|
| 0, 5, 12, 15 | Pines de arranque (*strapping*) o con pulsos al arrancar |
| 1, 3 | UART0 (USB) |
| 6–11 | Memoria flash |
| 14 | Emite pulsos al arrancar |
| 34–39 | Sólo entrada y sin pull-up interno |

Libres: 13, 18, 19, 21, 22, 23 (y 4 con la opción T1).

## 4. Estado durante el arranque

Mientras el ESP32 arranca, GPIO25, 26 y 27 quedan en alta impedancia:
- RL1 desactivado ⇒ **PTC sin permiso**.
- RL3 desactivado ⇒ contacto NC cerrado ⇒ **FAN_P encendido**.
- RL4 desactivado ⇒ FAN_C sin forzar (sigue lo que mande el control).

## 5. Constantes en `config.h`

```cpp
constexpr int PIN_DOOR_NO          = 32;
constexpr int PIN_DOOR_NC          = 33;
constexpr int PIN_PTC_PERMIT       = 25;  // ALTO = permitido (RL1)
constexpr int PIN_FAN_P_OFF_PERMIT = 26;  // ALTO = se permite apagar FAN_P (RL3)
constexpr int PIN_FAN_C_FORCE      = 27;  // ALTO = forzar FAN_C (RL4)
constexpr int PIN_CTRL_RX          = 16;  // UART2
constexpr int PIN_CTRL_TX          = 17;
constexpr int PIN_TH_SENSE         = 4;   // sólo con la opción T2
constexpr int PIN_LED              = 2;
```

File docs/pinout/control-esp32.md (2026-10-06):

# Pinout — ESP32 DevKit V1 (nodo de CONTROL)

> Regla de máxima prioridad: este controlador hace **sólo control** ([ADR-0012](../decisiones/ADR-0012-regla-mega-control-nano-sis.md)).

Placa: **ESP32 DevKit V1** (DOIT, ESP32-WROOM-32, 30 pines) [CONFIRMADO, 2026-10-06]. Es el mismo modelo que la placa del SIS: **etiquetar las dos placas** ("CONTROL" y "SIS") para no intercambiarlas. Lógica a **3,3 V**: ningún pin tolera 5 V.
Sólo módulos y dispositivos, sin componentes sueltos ([ADR-0013](../decisiones/ADR-0013-solo-modulos-y-dispositivos.md)). Estado: **[PROPUESTA]** salvo lo marcado.
Las constantes están en `firmware/control/src/config.h`.

## 1. Alimentación y pines de sistema

| Pin de la placa | Conexión | Notas |
|---|---|---|
| **VIN** | ← salida de **REG_A** (5V_A) | El regulador de 3,3 V de la placa alimenta el ESP32. Comprobar si la placa aísla el USB de VIN [VERIFICAR]; si no, no conectar el USB a la vez |
| **GND** | ← GND de REG_A → estrella de tierra | Común con el SIS y el HMI (obligatorio para los UART) |
| **3V3** | → VCC de M1, M2 (MAX6675), S1 (SHT31), S2 (SGP40) | Así todas sus señales son de 3,3 V |
| USB (UART0, GPIO1/3) | Programación, consola de servicio y registro CSV | No usar GPIO1/3 para otra cosa |

## 2. Pines usados

| GPIO | Dir. | Señal | Conecta a (componente.terminal) | Lógica | Constante |
|---|---|---|---|---|---|
| 32 | Entrada (pull-up interno) | Puerta NA | SW1.**NA** (la misma línea va al SIS GPIO32) | BAJO = contacto cerrado | `PIN_DOOR_NO` |
| 33 | Entrada (pull-up interno) | Puerta NC | SW1.**NC** (la misma línea va al SIS GPIO33) | BAJO = contacto cerrado | `PIN_DOOR_NC` |
| 25 | Salida | Calentar PTC | **SSR1.Entrada(+)**; SSR1.Entrada(−) → GND | ALTO = calentar | `PIN_SSR1` |
| 26 | Salida | Ventilador de circulación | **SSR2.Entrada(+)**; SSR2.Entrada(−) → GND | ALTO = encender | `PIN_FAN_C` |
| 27 | Salida | Apagar ventilador del PTC | **RL2.IN** (módulo con disparo ALTO; FAN_P en COM–NC, en paralelo con RL3 del SIS) | **ALTO = pedir apagado** | `PIN_FAN_P_OFF` |
| 21 | E/S | I2C SDA | S1.SDA, S2.SDA | I2C 100 kHz | `PIN_I2C_SDA` |
| 22 | Salida | I2C SCL | S1.SCL, S2.SCL | I2C | `PIN_I2C_SCL` |
| 18 | Salida | SPI SCK | M1.SCK, M2.SCK | SPI modo 0, 1 MHz | `PIN_SPI_SCK` |
| 19 | Entrada | SPI MISO | M1.SO, M2.SO | SPI | `PIN_SPI_MISO` |
| 23 | Salida | CS de TC1 | M1 (MAX6675).CS | BAJO = seleccionado | `PIN_CS_TC1` |
| 13 | Salida | CS de TC2 | M2 (MAX6675).CS | BAJO = seleccionado | `PIN_CS_TC2` |
| 17 | Salida | UART2 TX → SIS | SIS **GPIO16 (RX2)** | UART 115200 8N1 | `PIN_SIS_TX` |
| 16 | Entrada | UART2 RX ← SIS | SIS **GPIO17 (TX2)** | UART | `PIN_SIS_RX` |
| 4 | Salida | UART1 TX → HMI | HMI **IO32** | UART 115200 8N1 | `PIN_HMI_TX` |
| 35 | Entrada (sólo entrada) | UART1 RX ← HMI | HMI **IO25** | UART | `PIN_HMI_RX` |
| 2 | Salida | LED de la placa | LED integrado | Estado / falla | `PIN_LED` |

SW1.COM va a GND. MAX6675 no recibe datos: no se conecta MOSI (`SPI.begin(18, 19, -1, -1)`).
UART1 se reasigna a GPIO4/GPIO35 (sus pines por defecto, 9/10, son de la memoria flash).
GPIO35 no tiene pull-up interno: con el HMI desconectado la línea queda al aire y puede llegar ruido; el CRC lo descarta.

El control y el SIS usan **los mismos números de pin** para la puerta (32/33), las salidas (25/26/27), el SPI (18/19/23) y el UART entre ellos (16/17, cruzados): TX de uno (17) al RX del otro (16).

## 3. Pines que no se usan a propósito

| GPIO | Motivo |
|---|---|
| 0, 5, 12, 15 | Pines de arranque (*strapping*) o con pulsos al arrancar |
| 1, 3 | UART0 (USB) |
| 6–11 | Memoria flash |
| 14 | Emite pulsos al arrancar |
| 34, 36, 39 | Sólo entrada y sin pull-up interno (libres) |

Libres para ampliaciones: 34, 36 (VP), 39 (VN), sólo como entradas.

## 4. Estado durante el arranque

Mientras el ESP32 arranca, los GPIO usados quedan en alta impedancia:
- GPIO25 al aire ⇒ SSR1 debe quedar apagado [VERIFICAR en F3]. Además, el SIS retira el permiso (RL1) al dejar de recibir `HB_CTRL`.
- GPIO26 al aire ⇒ SSR2 apagado (FAN_C sólo si el SIS lo fuerza con RL4).
- GPIO27 al aire ⇒ RL2 sin energizar ⇒ **FAN_P encendido**.

## 5. Constantes en `config.h`

```cpp
constexpr int PIN_DOOR_NO = 32;
constexpr int PIN_DOOR_NC = 33;
constexpr int PIN_SSR1 = 25;
constexpr int PIN_FAN_C = 26;
constexpr int PIN_FAN_P_OFF = 27;  // ALTO = pedir apagado de FAN_P (RL2)
constexpr int PIN_I2C_SDA = 21;
constexpr int PIN_I2C_SCL = 22;
constexpr int PIN_SPI_SCK = 18;
constexpr int PIN_SPI_MISO = 19;
constexpr int PIN_CS_TC1 = 23;
constexpr int PIN_CS_TC2 = 13;
constexpr int PIN_SIS_RX = 16;     // UART2
constexpr int PIN_SIS_TX = 17;
constexpr int PIN_HMI_RX = 35;     // UART1 reasignado
constexpr int PIN_HMI_TX = 4;
constexpr int PIN_LED = 2;
```

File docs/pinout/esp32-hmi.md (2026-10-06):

# Pinout — ESP32-32E con pantalla 3.2" (nodo HMI)

Placa E32R32P ([wiki](https://www.lcdwiki.com/3.2inch_ESP32-32E_Display)). Lógica a **3,3 V** (las entradas **no** toleran 5 V).
El HMI **no se conecta a nada del proceso** [CONFIRMADO]: sólo alimentación y el enlace con el control (ESP32 DevKit V1 de control).
Las constantes van en `firmware/hmi/src/display.h`.

## 1. Pines internos de la placa (fijos, verificados en la wiki)

No se reasignan; el firmware sólo los configura.

| GPIO | Uso en la placa | Uso en el firmware | Notas |
|---|---|---|---|
| IO15 | LCD CS | LovyanGFX panel `pin_cs` | Pin de arranque (strapping) |
| IO2 | LCD DC | `pin_dc` | Pin de arranque |
| IO14 | SPI SCLK (LCD y táctil) | `pin_sclk` | |
| IO13 | SPI MOSI (LCD y táctil) | `pin_mosi` | |
| IO12 | SPI MISO (LCD y táctil) | `pin_miso` | Pin de arranque: no forzarlo a ALTO al encender |
| EN | Reset del ESP32 y del LCD | `pin_rst = -1` | |
| IO27 | Retroiluminación | `Light_PWM`, ALTO = encendida | |
| IO33 | Táctil XPT2046 CS | `Touch_XPT2046 pin_cs` | Mismo bus SPI que el LCD (`bus_shared = true`) |
| IO36 | Táctil IRQ | `pin_int` | Sólo entrada; BAJO = toque |
| IO5, IO18, IO19, IO23 | Tarjeta microSD (CS, SCLK, MISO, MOSI) | Sin uso por ahora | IO18/19/23 también en el conector SPI |
| IO4, IO26 | Altavoz: habilitación y DAC | Sin uso por ahora | |
| IO22, IO16, IO17 | LED RGB (rojo, verde, azul), **ánodo común: BAJO = encendido** | Poner los tres en ALTO al arrancar (apagado) | IO16/IO17 son los pines por defecto de UART2: **por eso UART2 se reasigna** (§2) |
| IO34 | ADC de batería | Sin uso | Sólo entrada |
| IO0 | Botón BOOT | Sin uso (arranque en modo descarga) | Pin de arranque |
| IO1, IO3 | UART0 (TX0/RX0) → conversor USB **CH340C** | Consola de depuración por USB-C | |

## 2. Conexiones externas usadas

| Conector de la placa | Pin | Dir. | Señal | Conecta a | Elementos en la línea | Constante |
|---|---|---|---|---|---|---|
| **I2C (1,25 mm, 4 pines)** | **IO25** | Salida | UART2 TX → control | Control **GPIO35 (RX1)** | Directo (ambos a 3,3 V) | `PIN_LINK_TX = 25` |
| **I2C (1,25 mm, 4 pines)** | **IO32** | Entrada | UART2 RX ← control | Control **GPIO4 (TX1)** | Directo (ambos a 3,3 V) | `PIN_LINK_RX = 32` |
| I2C (1,25 mm, 4 pines) | 3V3 | — | **No conectar** | — | — | — |
| I2C (1,25 mm, 4 pines) | GND | — | Tierra del enlace | GND común | — | — |
| USB-C | 5 V / GND | Entrada | Alimentación | **5V_A** (REG_A) | Por cable USB-C o pigtail | — |

Configuración del enlace en el firmware (el orden de argumentos es RX y luego TX):

```cpp
Serial2.begin(115200, SERIAL_8N1, /*rx=*/32, /*tx=*/25);
```

**[VERIFICAR con multímetro]** el orden de los 4 pines del conector I2C y que incluya GND y 3V3. Si no incluyera GND, tomarla del conector serie.

El control (ESP32 DevKit V1 de control) y el HMI trabajan a 3,3 V: la conexión es directa. Durante el prototipo del HMI (que usa un simulador) no hace falta conectar nada.

**[PROPUESTA]** Usar UART2 en el conector I2C en vez de UART0 tiene dos ventajas: UART0 queda libre para depurar por USB y se evita la contención con el CH340C, que también maneja IO3.

## 3. Conectores sin uso

| Conector | Pines | Uso |
|---|---|---|
| Serie (1,25 mm, 4P) | RXD0 (IO3), TXD0 (IO1), GND, VCC | **Sin señales.** Su VCC podría servir de entrada de 5 V en lugar del USB-C **[VERIFICAR]** |
| SPI periférico (1,25 mm, 4P) | IO21 (CS), IO18, IO19, IO23 | Sin uso |
| Entradas de expansión (1,25 mm, 2P) | IO35, IO39 | Sin uso (sólo entrada) |
| Batería (1,25 mm, 2P) | — | Sin uso |
| Altavoz (1,25 mm, 2P) | — | Sin uso por ahora |
| microSD | — | Sin uso por ahora (registro en SD: decisión abierta A-7) |

## 4. Estado durante el reinicio

El HMI no maneja nada del proceso: un reinicio sólo deja la pantalla en negro. Si dura más de 10 s con un ciclo activo, el control cancela y enfría.

## 5. Constantes (en `display.h`, con nombres equivalentes)

```cpp
// Pantalla y táctil (fijos de la placa)
constexpr int PIN_LCD_CS   = 15;
constexpr int PIN_LCD_DC   = 2;
constexpr int PIN_SPI_SCLK = 14;
constexpr int PIN_SPI_MOSI = 13;
constexpr int PIN_SPI_MISO = 12;
constexpr int PIN_LCD_RST  = -1;   // compartido con EN
constexpr int PIN_LCD_BL   = 27;   // ALTO = encendida
constexpr int PIN_TOUCH_CS = 33;
constexpr int PIN_TOUCH_IRQ = 36;
// LED RGB, ánodo común (BAJO = encendido)
constexpr int PIN_LED_R = 22;
constexpr int PIN_LED_G = 16;
constexpr int PIN_LED_B = 17;
// Enlace con el control, ESP32 DevKit V1 de control (UART2 reasignado al conector I2C)
constexpr int PIN_LINK_TX = 25;
constexpr int PIN_LINK_RX = 32;
constexpr uint32_t LINK_BAUD = 115200;
```

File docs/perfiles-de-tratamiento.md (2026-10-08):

# Perfiles de tratamiento

El usuario elige **opciones discretas**; nunca ve ni introduce temperaturas, porcentajes o minutos.

| Categoría | Opciones |
|---|---|
| Calzado (4) | Cuero · Deportivo · Bota · Sintético (nombres provisionales) |
| Intensidad (3) | Suave · Media · Intensa |
| Duración (3) | Corta · Media · Larga |

## Reglas

- El HMI envía sólo `calzado_id` (0–3), `intensidad_id` (0–2) y `duracion_id` (0–2). El control rechaza ids fuera de rango.
- La tabla de valores vive en el control ([ADR-0007](decisiones/ADR-0007-perfiles-en-el-control.md)); los ids, en `firmware/compartido/qs_protocol.h`; los valores, en `firmware/control/src/config.h`.
- La intensidad fija la temperatura según el calzado; la duración fija el tiempo de tratamiento a temperatura.
- El SIS no conoce el perfil: tiene un único límite fijo.
- 4 × 3 × 3 = 36 combinaciones: todas se prueban.

## Valores de partida (hipótesis, a validar con ensayos)

Temperatura del aire de recámara (TC1):

| Calzado | Suave | Media | Intensa |
|---|---|---|---|
| Cuero | 35 °C | 40 °C | 45 °C |
| Deportivo (tela/malla) | 40 °C | 45 °C | 50 °C |
| Bota (forrada/gruesa) | 40 °C | 45 °C | 50 °C |
| Sintético (goma/adhesivos) | 38 °C | 42 °C | 48 °C |

Duración del tratamiento:

| Corta | Media | Larga | Tope global |
|---|---|---|---|
| 5 min | 10 min | 25 min | 120 min |

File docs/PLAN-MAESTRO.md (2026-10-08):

# Plan maestro de implementación — QuitaSicote3000

Versión 7 · 2026-10-06 · Electrónica y firmware de todo el sistema.

---

## 0. Cómo leer este documento (personas y agentes de IA)

### 0.1 Propósito
Este documento es la **referencia principal** para implementar el sistema completo: electrónica, firmware de los tres nodos, pruebas y orden de trabajo. Está escrito para que otra persona u otro agente de IA pueda continuar el proyecto **sin el historial de conversación**.

### 0.2 Regla de máxima prioridad [CONFIRMADO]

> **El control y el SIS corren en dos ESP32 DevKit V1 distintos (uno para cada uno). Esta separación se mantiene estrictamente en todo el proyecto** ([ADR-0012](decisiones/ADR-0012-regla-mega-control-nano-sis.md)).

- Todo lo que sea **control** (ciclo, perfiles, regulación, ventiladores, sensores de proceso) corre en el **ESP32 DevKit V1 de control**.
- Todo lo que sea **seguridad** (funciones SIF, permiso del PTC, vetos, forzados, enclavamientos) corre en el **ESP32 Dev Kit**.
- Si una salida necesita a la vez la orden del control y una condición de seguridad, se combina **por hardware** con **contactos de módulos de relé** (NC en paralelo = AND para apagar; NA en paralelo = OR para encender). **Nunca** se mueve una función de un controlador al otro.
- El HMI (ESP32-32E) no hace ni control ni seguridad.

**Preferencias de hardware [CONFIRMADO]** ([ADR-0013](decisiones/ADR-0013-solo-modulos-y-dispositivos.md)):
- Sólo **módulos o dispositivos**: nada de resistencias, condensadores, diodos, transistores ni circuitos integrados sueltos.
- **Sin** módulos optoacopladores ni convertidores de nivel lógico.
- **Sin** fusibles ni caja de fusibles.

### 0.3 Etiquetas de estado

| Etiqueta | Significado | ¿Se puede cambiar sin consultar? |
|---|---|---|
| **[CONFIRMADO]** | Dato o decisión dada explícitamente por el usuario | **No** |
| **[DECIDIDO]** | Propuesta aceptada por el usuario (ADR aceptado) | No, salvo error técnico demostrado |
| **[PROPUESTA]** | Sugerencia técnica no confirmada por el usuario | Sí, justificándolo |
| **[POR MEDIR]** | Valor que debe salir de un ensayo; el número escrito es provisional | Sí, con el resultado del ensayo |
| **[VERIFICAR]** | Dato externo (hoja de datos, placa) aún no comprobado | Sí, al comprobarlo |
| **[ABIERTO]** | Falta una decisión del usuario | No: preguntar |

### 0.4 Reglas para quien modifique el proyecto
1. La regla y las preferencias de §0.2 están por encima de cualquier otra consideración.
2. Ante un conflicto entre este plan y otro documento del repo, **no elijas en silencio**: corrige el que esté mal y anótalo en el registro de cambios (§15).
3. El SIS no acepta umbrales ni órdenes que relajen la seguridad por la comunicación: **lo que recibe sólo puede restringir**.
4. El HMI **no decide nada**: muestra lo que envía el control y hace solicitudes. Nunca envía temperaturas ni minutos.
5. Los nombres de constantes de la §12 son los que deben usarse en el código.
6. Documentación y comentarios en **español**; identificadores de código en **inglés**.
7. Al terminar una fase, actualiza su estado en la §10 y el registro de cambios.

### 0.5 Documentos relacionados
| Documento | Contenido |
|---|---|
| [pinout/](pinout/README.md) | **Pinout de cada controlador**: única fuente de números de pin |
| [requisitos.md](requisitos.md) | Requisitos RF/RS/RD |
| [arquitectura.md](arquitectura.md) | Resumen de nodos y responsabilidades |
| [maquina-de-estados.md](maquina-de-estados.md) | Ciclo del control (resumen) |
| [perfiles-de-tratamiento.md](perfiles-de-tratamiento.md) | Calzado × intensidad × duración |
| [comunicacion.md](comunicacion.md) | Enlaces (resumen; el detalle de bytes está en §6) |
| [seguridad-sis.md](seguridad-sis.md) | SIF y pruebas V-xx (resumen) |
| [decisiones/](decisiones/README.md) | ADRs |
| [../firmware/hmi/PLAN.md](../firmware/hmi/PLAN.md) | Plan detallado de la interfaz LVGL |

---

## 1. Qué es el sistema

Equipo **doméstico** [CONFIRMADO] que elimina el mal olor del calzado haciendo circular aire caliente por una recámara cerrada. El usuario elige tipo de calzado, intensidad y duración en una pantalla táctil; el equipo calienta con una resistencia PTC, ventila y enfría.

### 1.1 Nodos [CONFIRMADO]

| Nodo | Placa | Función |
|---|---|---|
| **Control** | **ESP32 DevKit V1** n.º 1 (DOIT, ESP32-WROOM-32, 30 pines) | Ciclo de tratamiento, sensores de proceso, SSR del PTC y ventiladores |
| **SIS** | **ESP32 DevKit V1** n.º 2 (mismo modelo, placa distinta) | Seguridad independiente: relé de permiso del PTC, relés de veto y forzado de ventiladores, enclavamientos |
| **HMI** | ESP32-32E con pantalla 3.2" (E32R32P) | Interfaz táctil; **sólo comunicación**, sin entradas ni salidas de proceso |

Los tres trabajan a **3,3 V**: se conectan entre sí directamente.

### 1.2 Capas de protección
```
Capa 3  Termostato bimetálico 80 °C en serie con el PTC   → hardware puro
Capa 2  SIS (ESP32 Dev Kit): su termopar y relé de permiso → software mínimo e independiente
Capa 1  Control (ESP32 DevKit V1 de control): límites de proceso sobre el SSR → lógica de proceso
```
Cada capa puede apagar el PTC **por sí sola**: TH1 abre el circuito, el SIS abre RL1, el control apaga SSR1.

### 1.3 Datos confirmados por el usuario (procedencia)
- **Control y SIS en dos ESP32 DevKit V1 separados, estrictamente** (máxima prioridad). Antes fueron Arduino Mega y Nano, y después ESP32-S3 y ESP32 Dev Kit: se cambiaron.
- Producto doméstico; se controla **sólo desde la pantalla**; **no hay botón físico de paro**.
- La pantalla ESP32-32E sólo se comunica.
- 3 termopares tipo K con 3 MAX6675; SHT31 (T/HR); SGP40 (VOC).
- 2 SSR de DC: uno para el PTC y otro para el ventilador de circulación.
- PTC de **100 W a 12 V** con ventilador propio; ese ventilador tiene alimentación separada y lo conmuta un **módulo de relé de 12 V** (configurable; se eligió **NC + disparo por nivel alto**).
- **Otro módulo de relé en serie con el PTC** como permiso del SIS.
- Ventilador de la cámara de circuitos conectado **directo a 12 V**.
- Todos los ventiladores son de **12 V y 2 cables** (sin tacómetro).
- **Un solo termostato bimetálico de 2 cables, 80 °C, rearme automático.** "No hay ninguna situación donde deba alcanzarse esa temperatura a menos que haya fuego."
- **Sólo módulos o dispositivos**; **sin** optoacopladores, **sin** convertidores de nivel, **sin** fusibles ni caja de fusibles, sin fusible térmico.
- **Dos reguladores de 5 V** (uno para el control y otro para el SIS).
- Limit switch de puerta: se usan **ambos contactos, NA y NC**.
- Fuente externa de **12 V / 20 A**. Corriente de arranque del PTC **desconocida**.
- Inicio de ciclo **sólo con la puerta cerrada**. Pausa máxima **5 min**.
- Enclavado persistente y **bloqueo tras 2 eventos** del termostato (reformulación pendiente, A-11).
- **4 tipos de calzado**, intensidad y duración con **3 opciones** cada una, sin valores ni porcentajes visibles.
- Pantalla en **horizontal**.

---

## 2. Estado actual (2026-10-06)

| Área | Estado |
|---|---|
| Documentación de arquitectura | Hecha (este plan + `docs/`) |
| Código | **Primera versión escrita (2026-10-06)**: protocolo, SIS, control y HMI compilan; sin probar en hardware |
| Plan del HMI | Pantallas escritas con LVGL 9; faltan las fuentes con acentos y la prueba en la placa |
| Hardware | Faltan, además de lo de §1.3: los dos ESP32 DevKit V1, RL1 (módulo de relé de 30 A), RM1 (módulo de 2 relés), REG_A, REG_B |
| Ensayos | Ninguno |

---

## 3. Requisitos clave (resumen)

Detalle en [requisitos.md](requisitos.md). Los que más condicionan el diseño:

- **RS-01** El PTC nunca se energiza con la puerta abierta.
- **RS-02** El PTC nunca supera el límite de seguridad aunque falle el control.
- **RS-03** El PTC nunca queda energizado sin flujo de aire.
- **RS-04** Pérdida de alimentación, de comunicación o de sensor ⇒ calentador apagado.
- **RS-05** Un fallo del control no puede desactivar al SIS.
- **RF-03** Inicio sólo con la puerta cerrada (HMI, control y SIS lo comprueban).
- **RD-03** Si el control pierde al HMI más de 10 s durante un ciclo, cancela y enfría.
- **RD-04** Tras un corte de energía, el ciclo no se reanuda.

---

## 4. Decisiones

### 4.1 Tomadas

| ID | Decisión | Estado |
|---|---|---|
| — | **Control y SIS en dos ESP32 DevKit V1 separados, estrictamente** | [CONFIRMADO] ([ADR-0012](decisiones/ADR-0012-regla-mega-control-nano-sis.md), [ADR-0002](decisiones/ADR-0002-mcu-del-sis.md)) |
| A-1 | El SIS corta el PTC con un **módulo de relé (RL1) en serie** | [DECIDIDO] ([ADR-0010](decisiones/ADR-0010-permiso-ptc-modulo-rele.md)) |
| A-2 | **Sólo módulos o dispositivos**; sin optoacopladores ni convertidores de nivel | [CONFIRMADO] ([ADR-0013](decisiones/ADR-0013-solo-modulos-y-dispositivos.md)) |
| A-3 | **Dos reguladores de 5 V** independientes | [CONFIRMADO] |
| A-9 | Enlaces directos a 3,3 V entre los tres ESP32 | [DECIDIDO] (consecuencia del cambio de controladores) |
| A-13 | Control y SIS: **ESP32 DevKit V1** (uno cada uno) | [CONFIRMADO] 2026-10-06 |
| A-10 | **Sin fusibles ni caja de fusibles**: la única protección contra cortocircuitos es la de la propia fuente | [CONFIRMADO]; riesgo aceptado (§13) |

### 4.2 Abiertas

| ID | Pregunta | Opciones | Recomendación | Bloquea |
|---|---|---|---|---|
| **A-11** | **Dónde cablear el termostato bimetálico** (TH1, 2 cables) | **T1**: en serie con los 12 V del PTC (barrera independiente de todo, pero el SIS no puede leerlo). **T2**: en serie con la señal de 3,3 V del SIS hacia RL1, leído por un pin del SIS (se puede leer y enclavar, pero si RL1 se suelda el termostato ya no corta). Detalle en [ADR-0008](decisiones/ADR-0008-termostato-rearme-automatico.md) | **T1**, con el bloqueo tras 2 eventos aplicado a los eventos térmicos que el SIS detecta (SIF-01, SIF-03, SIF-08) | F3, F4 |
| **A-12** | ¿Recuperar la lectura de los nodos de 12 V con un **módulo sensor de voltaje** (0–25 V, salida analógica)? Permitiría leer el termostato, el contacto de RL1, un SSR1 en corto y la tensión del ventilador del PTC | Sí / no | Opcional; recomendable si se acepta ese tipo de módulo | F3 |
| **A-4** | Si el SIS deja de recibir al control con el permiso concedido, ¿disparo enclavado o sólo retirar el permiso? | — | Disparo enclavado | F4 |
| **A-5** | Procedimiento de servicio tras el bloqueo | Ver §7.9 | Comando por USB del control + secuencia de puerta | F4 |
| **A-6** | ¿VOC/HR como criterio de fin anticipado? | Sí / no / sólo informativo | Sólo informativo hasta tener datos | F9 |
| **A-7** | Registro de ciclos | CSV por USB del control / SD del HMI | CSV por USB desde el principio; SD después | F5 |
| **A-8** | Nombres de los 4 calzados | — | Cuero, Deportivo, Bota, Sintético | F1 |

---

## 5. Electrónica

### 5.0 Componentes y designadores

| Ref. | Componente | Estado |
|---|---|---|
| PSU | Fuente externa 12 V / 20 A | [CONFIRMADO] |
| J1 | Conector de entrada de 12 V con polaridad (p. ej. XT60): protege contra polaridad inversa | [PROPUESTA] |
| TH1 | Termostato bimetálico 80 °C, 2 cables, NC, rearme automático | [CONFIRMADO]; cableado [ABIERTO A-11] |
| **RL1** | **Módulo de relé de 12 V, permiso del PTC**: contacto **NA**, disparo **ALTO** compatible con 3,3 V, contacto **≥ 30 A en DC**. Lo maneja el SIS | Tipo [DECIDIDO]; especificación [PROPUESTA] |
| SSR1 | SSR DC-DC (MOSFET) para el PTC. Lo maneja el control | [CONFIRMADO]; especificación [PROPUESTA] |
| SSR2 | SSR DC-DC para el ventilador de circulación. Lo maneja el control | [CONFIRMADO] |
| RL2 | Módulo de relé de 12 V del ventilador del PTC: contacto **NC**, disparo **ALTO**. Lo maneja el control | [CONFIRMADO] |
| **RM1** | **Módulo de 2 relés** (disparo **ALTO** compatible con 3,3 V) para el SIS: **RL3** = veto del apagado de FAN_P (contacto **NC**, en paralelo con RL2); **RL4** = forzado de FAN_C (contacto **NA**, en paralelo con SSR2) | [PROPUESTA] |
| PTC | Calefactor PTC 100 W / 12 V | [CONFIRMADO] |
| FAN_P | Ventilador del PTC (12 V, 2 cables) | [CONFIRMADO] |
| FAN_C | Ventilador de circulación (12 V, 2 cables) | [CONFIRMADO] |
| FAN_B | Ventilador de la cámara de circuitos (12 V, 2 cables) | [CONFIRMADO] |
| REG_A | Módulo regulador conmutado (buck) 12 → 5 V, ≥ 2 A: lado control (ESP32 DevKit V1 de control + HMI) | [CONFIRMADO]; especificación [PROPUESTA] |
| REG_B | Módulo regulador conmutado 12 → 5 V, ≥ 1 A: lado SIS | [CONFIRMADO]; especificación [PROPUESTA] |
| SW1 | Limit switch de puerta SPDT (COM, NA, NC) | [CONFIRMADO] |
| TC1–TC3 + M1–M3 | Termopar K + módulo MAX6675 (alimentado a 3,3 V) | [CONFIRMADO] |
| S1 | Módulo SHT31 (I2C 0x44), alimentado a 3,3 V | [CONFIRMADO] |
| S2 | Módulo SGP40 (I2C 0x59), alimentado a 3,3 V | [CONFIRMADO] |
| MCU_C | ESP32 DevKit V1 n.º 1 (control) | [CONFIRMADO] |
| MCU_S | ESP32 DevKit V1 n.º 2 (SIS) | [CONFIRMADO] |
| HMI | Placa ESP32-32E 3.2" | [CONFIRMADO] |

### 5.1 Presupuesto de corriente (12 V)

| Carga | Corriente | Estado |
|---|---|---|
| PTC en régimen | ≈ 8,3 A | Calculado (100 W / 12 V) |
| PTC en el arranque | Mayor: un PTC frío tiene menos resistencia | [POR MEDIR] F7 |
| FAN_P, FAN_C, FAN_B | ≈ 0,1–0,5 A cada uno | [POR MEDIR] |
| Bobinas de RL1, RL2, RL3, RL4 | ≈ 0,07–0,2 A cada una | [VERIFICAR] modelo |
| Lógica a 5 V (ESP32 DevKit V1 de control, ESP32, HMI con retroiluminación, sensores) | ≈ 0,7 A a 5 V ⇒ ≈ 0,35 A a 12 V | Estimado (radios apagadas) |
| **Total** | **≈ 10 A en régimen** | La fuente de 20 A tiene margen |

### 5.2 Distribución de potencia

Con la opción **T1** de A-11 (termostato en la línea del PTC):

```
PSU 12 V ─ J1 ─┬─ TH1 ── RL1 (COM→NA) ── PTC(+)   PTC(−) ── SSR1 salida(+)  SSR1 salida(−) ── GND
               │
               ├─ RL2 (COM→NC) ──┐
               ├─ RL3 (COM→NC) ──┴── FAN_P(+)     FAN_P(−) ── GND        (NC en paralelo = AND para apagar)
               ├─ FAN_C(+)   FAN_C(−) ─┬─ SSR2 salida(+)  SSR2 salida(−) ── GND
               │                       └─ RL4 (COM→NA) ── GND            (NA en paralelo = OR para encender)
               ├─ FAN_B(+)   FAN_B(−) ── GND                             (siempre encendido)
               ├─ VCC de RL1, RL2 y RM1 (bobinas de 12 V)
               │
               ├─ REG_A ── 5V_A ──► ESP32 DevKit V1 de control (pin 5V), HMI (USB-C)
               └─ REG_B ── 5V_B ──► ESP32 Dev Kit (pin 5V/VIN)

3V3 del ESP32 DevKit V1 de control ──► M1, M2 (MAX6675), S1 (SHT31), S2 (SGP40)
3V3 del ESP32 Dev Kit ──► M3 (MAX6675)
```

Con la opción **T2**, TH1 sale de la línea del PTC (12 V directo a RL1) y pasa a la señal: `pin de permiso del SIS → TH1 → RL1.IN`, con un segundo pin del SIS leyendo el lado de RL1.IN.

Notas:
- **SSR1 y SSR2 en el lado bajo** (entre la carga y GND) [PROPUESTA], la configuración habitual de los SSR DC-DC [VERIFICAR con el modelo].
- **FAN_P no pasa por TH1, RL1 ni SSR1**: sigue funcionando cuando la rama del PTC está cortada.
- **Reguladores al pin 5V** de cada placa; el regulador de 3,3 V de la propia placa alimenta el ESP32 y los sensores.
- **Programación por USB**: con el regulador conectado al pin 5V, comprobar si la placa tiene un diodo entre el USB y el pin 5V [VERIFICAR]. Si no lo tiene, **no conectar el USB a la vez** que el regulador.
- **Sensores a 3,3 V**: alimentarlos desde el pin 3V3 de su placa, para que sus señales sean de 3,3 V. **Ninguna entrada de un ESP32 tolera 5 V.**
- **Módulos de relé y SSR manejados con 3,3 V**: deben activarse de forma fiable con 3,3 V en la entrada (disparo ALTO) [VERIFICAR en F3]. **No usar módulos con disparo por nivel bajo** alimentados a 5 V: con 3,3 V en la entrada podrían quedar a medio activar.
- **Sin pull-downs** (ADR-0013): cada módulo de relé y cada SSR debe quedar **desactivado con la entrada al aire**, porque así queda mientras su controlador arranca. Se comprueba en F3; un módulo que no lo cumpla se cambia.
- **Sin fusibles** [CONFIRMADO]: el cable principal y la rama del PTC deben soportar la corriente a la que actúa la protección de la fuente (≈ 20–25 A): **12 AWG (4 mm²)**. Los cables finos de ventiladores y módulos no quedan protegidos ante un cortocircuito (riesgo aceptado, §13).

### 5.3 Rama del PTC

- **Orden (T1)**: PSU → TH1 → RL1 (contacto NA) → PTC → SSR1 → GND. Cualquiera de los tres que abra apaga el PTC.
- **RL1** [DECIDIDO]: módulo de relé con disparo ALTO manejado por el SIS; energizado = permitido. **El contacto debe soportar la corriente del PTC en DC**: los módulos comunes de 10 A (relé tipo SRD) **no sirven**; usar uno de **30 A** (relé tipo SLA) y comprobar su especificación en DC [VERIFICAR]. RL1 se cierra al empezar a calentar y se abre al terminar.
- **TH1 (T1)**: el contacto bimetálico debe soportar ≈ 8,3 A en DC [VERIFICAR: los datos suelen darse para CA].
- **SSR1**: DC-DC de salida MOSFET, especificado para **≥ 40 A** si es un modelo genérico (los "25DD" de bajo costo suelen soportar mucho menos de lo indicado), con disipador [PROPUESTA]. Entrada de 3–32 V DC: comprobar que activa con 3,3 V [VERIFICAR].
- **Conmutación lenta** del SSR1: ventana proporcional de 2 s con mínimo 100 ms encendido/apagado (§8.6).
- **Cableado**: 12 AWG (4 mm²); terminales y conectores de ≥ 25 A; retorno propio a la estrella de tierra.

### 5.4 Ventiladores

| Ventilador | Lo maneja el control (ESP32 DevKit V1 de control) | Intervención del SIS (ESP32 Dev Kit) | Combinación | Reposo / falla |
|---|---|---|---|---|
| FAN_P (PTC) | RL2, **ALTO = pedir apagado** | RL3, **ALTO = permitir apagado** | Contactos **NC en paralelo**: se apaga sólo si RL2 **y** RL3 están energizados | Cualquier controlador sin alimentación o arrancando ⇒ su relé sin energizar ⇒ **encendido** |
| FAN_C (circulación) | SSR2, ALTO = encender | RL4, **ALTO = forzar encendido** | Contacto NA de RL4 **en paralelo** con la salida de SSR2 | Sin señales ⇒ apagado |
| FAN_B (cámara de circuitos) | — | — | — | Siempre encendido (directo a 12 V) |

- Si cae REG_A (control apagado) **o** REG_B (SIS apagado), el ventilador del PTC sigue girando.
- No hay sensado de tensión ni de giro en ningún ventilador (2 cables, sin módulos de lectura de 12 V).
- **FAN_B** debe tomar aire del exterior, no de la recámara (caliente, húmeda y con vapores), con rejilla.

### 5.5 Lo que el SIS no puede medir (ADR-0013)

Sin módulos de lectura de 12 V, el SIS **no** ve: el termostato (con T1), el contacto real de RL1, un SSR1 en corto ni la tensión del ventilador del PTC. Se compensa con:
- **TC3** montado junto a TH1: SIF-01 (sobretemperatura), SIF-03 (subida brusca) y SIF-08 (calentamiento sin efecto).
- **El control**: ante sobretemperatura pasa a FALLA y retira `heat_request`, con lo que el SIS abre RL1.
- Opción A-12 (módulo sensor de voltaje) o T2 (termostato leído por el SIS) para recuperar parte de esas lecturas.

### 5.6 Sensores

| Sensor | Bus / dirección | Nodo | Montaje |
|---|---|---|---|
| TC1 + M1 | SPI | Control | Aire de la recámara, cerca del calzado. Variable de control |
| TC2 + M2 | SPI | Control | Aire a la salida del PTC (unos cm aguas abajo). Límite y diagnóstico de flujo |
| TC3 + M3 | SPI | SIS | Aire en el punto más caliente en caso de falla, **junto a TH1, sin tocar las aletas del PTC** [POR MEDIR en F7] |
| S1 SHT31 | I2C 0x44 | Control | Recámara, fuera del chorro directo del PTC |
| S2 SGP40 | I2C 0x59 | Control | Trayecto de retorno o salida del aire, la zona **más fresca**: su rango de operación tiene un máximo cercano a 50 °C [VERIFICAR hoja de datos] |
| SW1 | Digital | Control y SIS | COM a GND; NA y NC directos a ambos controladores, con pull-up interno |

**MAX6675** (comportamiento para el firmware):
- Alimentar a **3,3 V** (rango 3,0–5,5 V) para que su salida SO sea de 3,3 V.
- Sólo termopar K. Resolución 0,25 °C. Conversión ≈ 220 ms: leer como mucho cada 250 ms por módulo; bajar CS aborta la conversión en curso.
- SPI modo 0, ≤ 4 MHz (usar 1 MHz). Se leen 16 bits: D15 = 0; D14–D3 = temperatura × 4 (12 bits); **D2 = 1 ⇒ termopar abierto**; D1 = 0; D0 indeterminado.
- Usar termopares de **unión aislada**: una unión que toque metal unido a GND (carcasa del PTC) altera la lectura.
- Cable de extensión tipo K, trenzado, lejos de los cables de potencia. Módulos lejos del calor.

**SHT31 / SGP40**: alimentar a 3,3 V; si el módulo trae resistencias de pull-up a su VIN, quedan a 3,3 V [VERIFICAR con los módulos].

**Puerta (SW1)**: puerta cerrada = actuador presionado ⇒ NA cerrado (BAJO) y NC abierto (ALTO). Tabla en §7.4. Si uno de los dos controladores está sin alimentación, sus diodos de protección pueden arrastrar las líneas a BAJO; el otro lee "NA BAJO + NC BAJO" = inválido = puerta abierta: falla segura.

### 5.7 Enlaces serie

Los tres controladores trabajan a 3,3 V: **conexión directa**, sin convertidores.

| Enlace | Conexión |
|---|---|
| Control ↔ SIS | UART2 del control ↔ UART2 del SIS (GPIO17 TX ↔ GPIO16 RX, cruzados) |
| Control ↔ HMI | UART1 del control (reasignado a GPIO4 TX / GPIO35 RX) ↔ UART2 del HMI, reasignado a IO25 (TX) / IO32 (RX) en el conector I2C de la placa |

Números de pin exactos: [pinout/](pinout/README.md). Velocidad: **115200 baudios 8N1** en ambos enlaces. GND común entre los tres nodos (obligatorio).
Depuración: USB de cada placa (UART0 por su conversor USB).

### 5.8 Asignación de pines

Cada controlador tiene su propio documento, con todos los pines, a qué terminal de qué componente va cada uno, la polaridad, el estado durante el arranque y las constantes del firmware:

| Controlador | Documento |
|---|---|
| ESP32 DevKit V1 (control) | [pinout/control-esp32.md](pinout/control-esp32.md) |
| ESP32 DevKit V1 (SIS) | [pinout/sis-esp32.md](pinout/sis-esp32.md) |
| ESP32-32E (HMI) | [pinout/esp32-hmi.md](pinout/esp32-hmi.md) |
| Cables entre controladores y polaridades | [pinout/README.md](pinout/README.md) |

Esos documentos son la **única fuente** de números de pin.

### 5.9 Tierra, cableado y ruido
- **Tierra en estrella** en el negativo de la fuente. Retornos separados para: rama del PTC, ventiladores, REG_A, REG_B. Los 8 A del PTC no comparten cable con la lógica.
- Cables de potencia y de señal separados; los de termopar, trenzados.
- Los módulos ya traen sus condensadores y diodos: no se añade nada suelto.
- Pasacables en la recámara; nada de cable de señal pegado al PTC.
- Sin fusibles: cables finos cortos, sujetos y lejos de material inflamable.

### 5.10 Comportamiento ante fallas de hardware

| Falla | Efecto inmediato | Cómo se detecta | Reacción |
|---|---|---|---|
| SSR1 en cortocircuito | PTC encendido sin orden | El control ve TC1 > setpoint + 5 °C; el SIS ve subir TC3 | El control pasa a FALLA y retira `heat_request` ⇒ el SIS abre RL1. Si no, SIF-01 abre RL1 |
| RL1 con contacto soldado | El SIS no puede cortar | **No se detecta** | SSR1 sigue controlando; TH1 (T1) como última barrera. Revisión periódica (F8) |
| RL1 no cierra | No calienta | Timeout de precalentamiento (control) | FALLA(5) |
| TH1 abierto (T1) | PTC sin corriente | Indirecto: SIF-08 (calentamiento sin efecto) | Disparo enclavado del SIS |
| RL2/RL3 o motor de FAN_P | PTC sin flujo | Subida rápida de TC3 (SIF-03), TC2 > máx. (control) | Disparo o FALLA; TH1 en última instancia |
| RL4 no cierra | El SIS no puede forzar FAN_C | No se detecta | FAN_P sigue siendo la protección principal |
| FAN_C parado | Recámara sin circulación | Timeout de precalentamiento, TC2 alto | FALLA |
| TC3 abierto o congelado | SIS ciego | Bit D2, rango, lectura congelada | SIF-04 |
| TC1/TC2 abiertos | Control ciego | Bit D2, rango | Falla clase A en el control |
| Cable de puerta cortado | — | Combinación NA/NC inválida | Se trata como puerta abierta |
| Cae REG_A | Control y HMI apagados; SSR1, SSR2 y RL2 sin señal | El SIS deja de recibir `HB_CTRL` | El SIS retira el permiso y fuerza FAN_C con RL4; FAN_P sigue |
| Cae REG_B | SIS apagado: RL1 abierto; RL3 y RL4 sin señal | El control deja de recibir `HB_SIS` | El control apaga SSR1 y pasa a FALLA(7); FAN_P sigue; FAN_C lo sigue manejando el control |
| Se cuelga el SIS | — | Task Watchdog (1 s) | Reinicio ⇒ ARRANQUE ⇒ RL1 abierto |
| Se cuelga el control | — | Task Watchdog y `HB_CTRL` | Reinicio ⇒ AUTOTEST; el SIS retira el permiso |
| Se cuelga el HMI | Sin interfaz | El control no recibe `HMI_HB` > 10 s | Cancela el ciclo y enfría |
| Cae la fuente de 12 V | Todo apagado | — | Al volver: AUTOTEST → LISTO, sin reanudar |
| Datos persistentes del SIS corruptos | — | CRC | Se trata como disparo enclavado que requiere rearme [PROPUESTA] |

---

## 6. Firmware común

### 6.1 Herramientas y estructura

- **PlatformIO**, framework **Arduino-ESP32** en los tres, con versión de plataforma **fijada**.
- **Toda la lógica corre en tareas de FreeRTOS** [CONFIRMADO, 2026-10-06]. En cada nodo las tareas comparten unas pocas variables protegidas por un mutex; los encargos entre tareas van por colas.
- **Pocos archivos y máxima legibilidad** [CONFIRMADO, 2026-10-06]: un `main.cpp` por nodo, leído de arriba abajo, más un `config.h` con todo lo ajustable. Sin capas ni bibliotecas propias.

```
firmware/
├─ compartido/qs_protocol.h   identificadores, mensajes y tramas (lo incluyen los tres)
├─ sis/src/                   config.h · main.cpp
├─ control/src/               config.h · sensors.h · main.cpp
└─ hmi/                       include/lv_conf.h · src/ display.h · ui.h · ui.cpp · main.cpp
```

- Cada `platformio.ini` tiene un único entorno e incluye `-I ../compartido`.
- No hay pruebas automáticas en PC (la lógica vive en las tareas): la validación es en banco, por inyección de fallas ([seguridad-sis.md](seguridad-sis.md)).

### 6.2 Unidades y representación

| Magnitud | Representación | Ejemplo |
|---|---|---|
| Temperatura en el SIS y el protocolo SIS | `int16_t` en **cuartos de grado** (`_q2`) | 68 °C = 272 |
| Temperatura hacia el HMI | `int16_t` en **décimas de grado** (`_x10`) | 45,3 °C = 453 |
| Humedad | `uint16_t` décimas de % | 38,5 % = 385 |
| Tiempos | `uint32_t` ms internamente; `uint16_t` segundos en el protocolo | |
| Valor inválido | `INT16_MIN` (0x8000) / `UINT16_MAX` (0xFFFF) | |

El SIS usa **aritmética entera**. El control puede usar `float` en el PID y en el algoritmo de VOC.

### 6.3 Trama

| Offset | Campo | Bytes | Notas |
|---|---|---|---|
| 0 | SOF = `0xAA` | 1 | |
| 1 | LEN = longitud del payload | 1 | 0–32; mayor ⇒ descartar |
| 2 | TYPE | 1 | §6.4 |
| 3 | SEQ | 1 | Contador del emisor, módulo 256 |
| 4 | PAYLOAD | LEN | Little-endian, estructuras empaquetadas |
| 4+LEN | CRC16 | 2 | Byte bajo primero |

- **CRC-16/CCITT-FALSE**: polinomio 0x1021, valor inicial 0xFFFF, sin reflexión, XOR final 0. Se calcula sobre los offsets 1 … 3+LEN (LEN, TYPE, SEQ y payload). Vector de prueba: `"123456789"` → **0x29B1**.
- Trama máxima: 38 bytes.
- **Parser**: máquina de estados byte a byte (esperar SOF → LEN → TYPE → SEQ → payload → CRC). Si LEN > 32 o el CRC falla, se descarta y se busca el siguiente `0xAA` **a partir del byte siguiente al SOF descartado**. Contadores de errores de CRC y de longitud.
- Sin relleno de bytes: la resincronización la dan SOF + LEN + CRC.

### 6.4 Mensajes

**Control ↔ SIS** (115200)

| TYPE | Nombre | Sentido | Periodo | Payload |
|---|---|---|---|---|
| 0x01 | `HB_CTRL` | Control → SIS | 100 ms | `u8 proto_ver`, `u8 cycle_state`, `u8 ctrl_flags`, `u8 reservado` |
| 0x02 | `HB_SIS` | SIS → Control | 100 ms | ver abajo (9 bytes) |
| 0x03 | `REQ_RESET` | Control → SIS | evento | `u8 magic = 0x5A`, `u16 trip_mask_ack` (debe coincidir con el `trip_mask` vigente) |
| 0x04 | `EVENT` | SIS → Control | evento | `u8 event`, `u16 trip_mask`, `u8 detalle` |
| 0x05 | `REQ_SERVICE` | Control → SIS | evento | `u8 magic1 = 0xC3`, `u8 magic2 = 0x3C`, `u8 op` (1 = desbloquear) |

`ctrl_flags` (HB_CTRL, **informativo**): b0 `heat_request` (el control está en un estado de calentamiento), b1 `fan_p_off_cmd` (salida a RL2), b2 `fan_c_cmd` (salida a SSR2), b3 `ssr1_cmd` (salida a SSR1).

`HB_SIS` (9 bytes):

| Offset | Tipo | Campo |
|---|---|---|
| 0 | u8 | `proto_ver` |
| 1 | u8 | `sis_state`: 0 ARRANQUE, 1 OK, 2 DISPARADO, 3 BLOQUEADO |
| 2 | u16 | `trip_mask`: b0–b7 = SIF-01…SIF-08 (b4 sin uso); b11 datos persistentes inválidos; b15 enclavado persistente |
| 4 | i16 | `tc3_q2` |
| 6 | u8 | `io_flags`: b0 puerta cerrada, b1 puerta inválida, b2 permiso del PTC (RL1), b3 apagado de FAN_P permitido (RL3), b4 FAN_C forzado (RL4), b5 termostato cerrado (sólo con T2 o A-12) |
| 7 | u8 | `thermal_events` (contador persistente, saturado) |
| 8 | u8 | reservado |

`EVENT.event`: 1 DISPARO, 2 REARME_OK, 3 REARME_RECHAZADO, 4 AUTOTEST_FALLIDO, 5 BLOQUEO, 6 DESBLOQUEO_SERVICIO.

**Control ↔ HMI** (115200)

| TYPE | Nombre | Sentido | Periodo | Payload |
|---|---|---|---|---|
| 0x10 | `HMI_HB` | HMI → Control | 500 ms | `u8 proto_ver`, `u8 screen_id` |
| 0x11 | `REQ_START` | HMI → Control | evento | `u8 shoe_id`, `u8 intensity_id`, `u8 duration_id` |
| 0x12 | `REQ_PAUSE` | HMI → Control | evento | — |
| 0x13 | `REQ_RESUME` | HMI → Control | evento | — |
| 0x14 | `REQ_CANCEL` | HMI → Control | evento | — |
| 0x15 | `REQ_ACK` | HMI → Control | evento | — (acepta "Completo" o la falla mostrada) |
| 0x16 | `REQ_REARM` | HMI → Control | evento | — (el control lo traduce a `REQ_RESET`) |
| 0x20 | `STATUS` | Control → HMI | 200 ms | ver abajo (28 bytes) |
| 0x21 | `RESP_START` | Control → HMI | evento | `u8 result`: 0 OK, 1 PUERTA_ABIERTA, 2 NO_LISTO, 3 ID_INVALIDO, 4 FALLA_ACTIVA |
| 0x22 | `LOG` | Control → HMI | — | Reservado para una fase posterior (registro en SD) |

`STATUS` (28 bytes):

| Offset | Tipo | Campo |
|---|---|---|
| 0 | u8 | `proto_ver` |
| 1 | u8 | `cycle_state` |
| 2 | u8 | `door`: 0 cerrada, 1 abierta, 2 inválida |
| 3 | u8 | `sis_state` |
| 4 | u16 | `trip_mask` |
| 6 | u8 | `fault_code` |
| 7 | u8 | `warn_flags`: b0 SHT31 en falla, b1 SGP40 en falla, b2 VOC en aprendizaje |
| 8 | u8 | `shoe_id` (0xFF sin ciclo) |
| 9 | u8 | `intensity_id` |
| 10 | u8 | `duration_id` |
| 11 | u8 | `pause_reason`: 0 ninguna, 1 puerta, 2 usuario |
| 12 | u16 | `remaining_s` |
| 14 | u16 | `total_s` |
| 16 | u16 | `pause_left_s` |
| 18 | i16 | `t_chamber_x10` (TC1) |
| 20 | u16 | `rh_x10` |
| 22 | u16 | `voc_index` (1–500) |
| 24 | u8 | `act_flags`: b0 PTC encendido (SSR1), b1 FAN_C, b2 FAN_P |
| 25 | u8 | `thermal_events` |
| 26 | u16 | reservado |

### 6.5 Enumeraciones compartidas (`qs_ids.h`)

`cycle_state`: 0 AUTOTEST, 1 LISTO, 2 PRECALENTAMIENTO, 3 TRATAMIENTO, 4 PAUSA, 5 ENFRIAMIENTO, 6 COMPLETO, 7 FALLA.

Perfiles: `shoe_id` 0 Cuero, 1 Deportivo, 2 Bota, 3 Sintético · `intensity_id` 0 Suave, 1 Media, 2 Intensa · `duration_id` 0 Corta, 1 Media, 2 Larga.

`fault_code`:

| Código | Nombre | Clase | Mensaje para el usuario (HMI) |
|---|---|---|---|
| 0 | NINGUNA | — | — |
| 1 | TC1_INVALIDO | A | Falla del sensor de temperatura de la recámara |
| 2 | TC2_INVALIDO | A | Falla del sensor de temperatura del calefactor |
| 3 | SHT31_FALLA | B | (aviso) Sensor de humedad no disponible |
| 4 | SGP40_FALLA | B | (aviso) Sensor de olor no disponible |
| 5 | PRECAL_TIMEOUT | A | El equipo no alcanzó la temperatura. Revisa los ventiladores |
| 6 | SOBRETEMP_SW | A | Temperatura demasiado alta |
| 7 | SIS_SIN_ENLACE | A | Falla interna de comunicación |
| 8 | SIS_DISPARO | A | Protección de seguridad activada (detalle en `trip_mask`) |
| 9 | (reservado) | — | — |
| 10 | PUERTA_INVALIDA | A | Falla del sensor de la puerta |
| 11 | TOPE_CICLO | — | (no es falla: fin por tiempo máximo) |
| 12 | HMI_SIN_ENLACE | — | Sólo se registra |
| 13 | BLOQUEO | A | Equipo bloqueado. Requiere servicio técnico |

**Clase A**: detiene el calentamiento y lleva a FALLA. **Clase B**: aviso; el ciclo continúa.

---

## 7. Firmware del SIS (ESP32 Dev Kit)

### 7.1 Principios
- Sólo funciones de seguridad (§0.2).
- **Wi-Fi y Bluetooth apagados** desde el arranque.
- Tres tareas de FreeRTOS (§7.3). La de seguridad corre cada **10 ms** con la prioridad más alta.
- **Task Watchdog** suscrito a la tarea de seguridad, con 1 s de tiempo; detector de caída de tensión (*brownout*) activo.
- Sin bibliotecas de terceros; MAX6675 por SPI del hardware; UART2 con `HardwareSerial`.
- Sin asignación dinámica después del arranque; sin `String`.
- Umbrales en `src/config.h` como `constexpr`. **Ninguno se recibe por la comunicación.**
- **La comunicación sólo puede restringir**: un dato del control puede retirar un permiso o provocar un disparo; nunca concede nada.

### 7.2 Archivos

`sis/src/config.h` (pines y umbrales) y `sis/src/main.cpp`, organizado en secciones: estado compartido → memoria no volátil → disparo, rearme y servicio → funciones de seguridad → tareas → arranque.

### 7.3 Tareas

| Tarea | Periodo | Qué hace |
|---|---|---|
| `taskSafety` (prioridad 5) | 10 ms | Leer la puerta, evaluar las SIF, escribir RL1/RL3/RL4, alimentar el watchdog |
| `taskThermocouple` (4) | 250 ms | Leer TC3, validarlo y guardar el historial de 10 s |
| `taskLink` (3) | 10 ms | Recibir `HB_CTRL` / `REQ_*`; enviar `HB_SIS` (cada 100 ms) y los `EVENT`; guardar en NVS |

La escritura en NVS la hace `taskLink`, no la tarea de seguridad: un corte nunca espera a la flash.

Tiempo de respuesta esperado puerta → RL1 abierto: antirrebote (30 ms) + un ciclo (10 ms) + liberación del relé (≈ 10 ms) ≈ **50 ms** (requisito < 200 ms).

### 7.4 Entradas e interpretación

**Puerta** (la combinación debe mantenerse 30 ms):

| NA | NC | Resultado |
|---|---|---|
| BAJO | ALTO | CERRADA |
| ALTO | BAJO | ABIERTA |
| BAJO | BAJO | INVÁLIDA (cortocircuito, switch dañado, otro controlador sin alimentación) |
| ALTO | ALTO | INVÁLIDA (cable o común cortado) |

INVÁLIDA se trata como ABIERTA y además se informa.

**TC3 válido** si: bit D2 = 0, −10 °C ≤ T ≤ 150 °C, y no está "congelado" (mismo valor crudo durante más de 60 s con el permiso concedido). Tres lecturas malas seguidas ⇒ inválido.

### 7.5 Funciones de seguridad (pseudocódigo)

```
door_ok  = (door == CERRADA)
hb_ok    = (ahora - ultimo_HB_CTRL) <= HB_CTRL_TIMEOUT_MS
permit   = valor actual de la salida a RL1

SIF-01  tc3_valid && tc3 >= T_SIS_MAX                               → disparo, evento térmico
SIF-02  !door_ok                                                    → inhibir (no enclava)
SIF-03  permit && (tc3 - tc3_hace_10s) >= SIF03_SLOPE_Q2_10S        → disparo, evento térmico [POR MEDIR]
SIF-04  !tc3_valid                                                  → disparo
SIF-05  (retirada: no hay realimentación eléctrica, ADR-0013)
SIF-06  !hb_ok && permit                                            → disparo [ABIERTO A-4]
SIF-07  permit continuo > SIF07_MAX_HEAT_MIN                        → disparo
        (el contador se reinicia sólo tras SIF07_COOL_OFF_MIN con el permiso retirado)
SIF-08  T1: "calentamiento sin efecto" (posible termostato abierto), evaluado en ventanas
          consecutivas de SIF08_WINDOW_MS con el permiso concedido:
          ssr1_cmd == 1 en >= SIF08_MIN_DUTY_PCT % de los HB de la ventana
          && tc3 bajó >= SIF08_DROP_Q2 entre el principio y el final                → disparo, evento térmico [POR MEDIR]
        T2: termostato leído abierto con el permiso ordenado        → disparo, evento térmico
```

Salidas (todas las decide el SIS con sus propias entradas):
```
RL1 permiso (ALTO = permitido)
   = (estado == OK) && door_ok && !disparo && hb_ok
     && heat_request(HB_CTRL) && tc3_valid && tc3 < T_SIS_MAX

RL3 permiso de apagado de FAN_P (ALTO = se permite; NC en paralelo con RL2 del control)
   = (estado == OK) && !permit && !disparo
     && permiso retirado desde hace >= FAN_P_OFF_HOLD_S
     && tc3_valid && tc3 < T_FRIO

RL4 forzar FAN_C (ALTO = forzar; NA en paralelo con SSR2 del control)
   = permit || disparo || (estado != OK) || !hb_ok || !tc3_valid || tc3 >= T_FRIO
```

Uso de los datos del control: `heat_request` sólo puede **quitar** el permiso; `ssr1_cmd` sólo puede **provocar** un disparo (SIF-08).

### 7.6 Estados del SIS

| Estado | RL1 | Entra cuando | Sale cuando |
|---|---|---|---|
| ARRANQUE | Abierto | Encendido o reinicio | Autotest correcto ⇒ OK (o DISPARADO/BLOQUEADO según los datos persistentes) |
| OK | Según §7.5 | Autotest o rearme correcto | Cualquier disparo ⇒ DISPARADO |
| DISPARADO | Abierto | Disparo | `REQ_RESET` válido ⇒ OK |
| BLOQUEADO | Abierto | 2.º evento térmico | Procedimiento de servicio (§7.9) |

**Autotest del SIS** (ARRANQUE, < 2 s):
1. Datos persistentes: magic y CRC correctos; si no, b11 y estado DISPARADO.
2. TC3 válido.
3. Puerta en una combinación válida (cerrada o abierta).

**Rearme** (`REQ_RESET` con `magic = 0x5A` y `trip_mask_ack == trip_mask`): se acepta sólo si la causa desapareció, `tc3 < T_SIS_RESET`, la puerta es válida y el estado no es BLOQUEADO. Responde `EVENT` REARME_OK o REARME_RECHAZADO.

### 7.7 Eventos térmicos y persistencia

- **Evento térmico**: disparo por SIF-01, SIF-03 o SIF-08 (con T1); con T2, también el termostato leído abierto.
- 1.er evento: disparo **enclavado y guardado**; rearme según §7.6.
- 2.º evento: **BLOQUEADO** hasta el procedimiento de servicio [DECIDIDO, ADR-0008; aplicación a eventos térmicos: ABIERTO A-11].

Persistencia en **NVS** (`Preferences`, espacio `"sis"`), un único bloque binario:

| Offset | Tipo | Campo |
|---|---|---|
| 0–1 | u16 | magic `0x5153` ("QS") |
| 2 | u8 | versión del formato (1) |
| 3 | u8 | `thermal_events` |
| 4–5 | u16 | `latched_trip_mask` |
| 6 | u8 | `lockout` (0/1) |
| 7 | u8 | CRC-8 (polinomio 0x31, inicio 0xFF) de los bytes 0–6 |

Escribir **sólo en eventos**.

### 7.8 Mensajes que el SIS ignora
Cualquier mensaje que no sea `HB_CTRL`, `REQ_RESET` o `REQ_SERVICE`. Ningún mensaje cambia umbrales.

### 7.9 Procedimiento de servicio [ABIERTO A-5, PROPUESTA]
Desbloquear exige **presencia física**:
1. El técnico envía `servicio desbloquear` por la consola USB del control, que manda `REQ_SERVICE` (op = 1).
2. El SIS sólo lo acepta si, en los 30 s siguientes, la puerta se abre y se cierra **3 veces** y TC3 < T_SIS_RESET.
3. Pone `lockout = 0` y `thermal_events = 0`, y emite `EVENT` DESBLOQUEO_SERVICIO.

---

## 8. Firmware de control (ESP32 DevKit V1 de control)

### 8.1 Principios
- Sólo funciones de control (§0.2). Sus límites de software son de proceso (capa 1), no funciones SIF.
- Wi-Fi y Bluetooth apagados (no se usan).
- Cinco tareas de FreeRTOS (§8.3). Las lecturas lentas (I2C) viven en la tarea de sensores, nunca en la del ciclo.
- **Task Watchdog** activo.
- Cada lectura lleva validez: una lectura mala suelta se tolera; tres seguidas dejan el sensor como inválido.
- Maneja SSR1, SSR2 (FAN_C) y RL2 (orden de apagar FAN_P). El SIS puede forzar o vetar los ventiladores con sus propios relés (RL3, RL4); el control lo ve en `HB_SIS`.

### 8.2 Archivos

`control/src/config.h` (pines, parámetros y tabla de perfiles), `control/src/sensors.h` (MAX6675, SHT31, SGP40) y `control/src/main.cpp`, organizado en secciones: estado compartido → fallas → solicitudes del HMI → máquina de estados → calefactor y ventiladores → tareas → arranque.

### 8.3 Tareas

| Tarea | Periodo | Qué hace |
|---|---|---|
| `taskCycle` (prioridad 5) | 10 ms | Puerta con antirrebote, máquina de estados, SSR1 y ventiladores, watchdog |
| `taskSisLink` (4) | 10 ms | Recibir `HB_SIS` y `EVENT`; enviar `HB_CTRL` (cada 100 ms), rearmes y servicio |
| `taskHmiLink` (3) | 10 ms | Recibir las solicitudes del HMI; enviar `STATUS` (cada 200 ms) |
| `taskSensors` (2) | 250 ms | Un MAX6675 por vuelta, alternando TC1 y TC2; cada segundo, SHT31 y SGP40 + índice VOC |
| `taskConsole` (1) | 100 ms | Comandos por USB; línea CSV cada segundo |

Bibliotecas: sólo "Gas Index Algorithm" de Sensirion; el SHT31 y el SGP40 se leen directamente por I2C (`sensors.h`). El índice VOC necesita muestras regulares a 1 Hz y tiene un periodo inicial de aprendizaje (`warn_flags` b2).

### 8.4 Máquina de estados

| Estado | Acciones al entrar | Mientras | Transiciones |
|---|---|---|---|
| AUTOTEST | SSR1 off, FAN_P on, FAN_C off | Comprobar: TC1/TC2 válidos; SHT31 responde; autotest del SGP40 (comando 0x280E → 0xD400); `HB_SIS` recibido con `sis_state` OK; puerta válida | Todo OK ⇒ LISTO. Falla A ⇒ FALLA. Sin `HB_SIS` en 5 s ⇒ FALLA(7) |
| LISTO | SSR1 off | Pedir el apagado de FAN_C y FAN_P sólo si TC2 < T_FRIO durante FAN_OFF_HOLD_S (el SIS debe permitir el de FAN_P) | `REQ_START` válido + puerta cerrada + SIS OK ⇒ PRECALENTAMIENTO (`RESP_START` 0). Si no ⇒ `RESP_START` con el motivo |
| PRECALENTAMIENTO | FAN_P on, FAN_C on; `heat_request = 1` | Control hacia `setpoint` cuando `HB_SIS` indique permiso concedido; contar `PREHEAT_TIMEOUT_MIN` | TC1 ≥ setpoint − TREAT_BAND_C ⇒ TRATAMIENTO. Puerta abierta o `REQ_PAUSE` ⇒ PAUSA. `REQ_CANCEL` ⇒ ENFRIAMIENTO. Timeout ⇒ FALLA(5). Falla A ⇒ FALLA |
| TRATAMIENTO | — | Control; el tiempo de tratamiento sólo avanza con TC1 ≥ setpoint − TREAT_BAND_C | Tiempo cumplido ⇒ ENFRIAMIENTO. Tope global ⇒ ENFRIAMIENTO (11). Puerta / pausa / cancelar / falla igual que arriba |
| PAUSA | SSR1 off, `heat_request = 0`, ventiladores on; `pause_left = 300 s` | Cuenta atrás | `REQ_RESUME` + puerta cerrada + SIS OK ⇒ PRECALENTAMIENTO (conserva el tiempo de tratamiento acumulado). `pause_left = 0` ⇒ ENFRIAMIENTO. `REQ_CANCEL` ⇒ ENFRIAMIENTO |
| ENFRIAMIENTO | SSR1 off, `heat_request = 0`, ventiladores on | — | TC1 < COOL_END_TC1_C y TC2 < COOL_END_TC2_C, o COOL_MAX_MIN ⇒ COMPLETO (o LISTO si viene de una falla o cancelación) |
| COMPLETO | — | Ventiladores hasta enfriar (regla de LISTO) | `REQ_ACK(0)` o apertura de la puerta ⇒ LISTO |
| FALLA | SSR1 off, `heat_request = 0`, ventiladores on | Mostrar `fault_code` | `REQ_ACK` con la causa resuelta ⇒ ENFRIAMIENTO ⇒ LISTO. SIS DISPARADO: `REQ_REARM` ⇒ `REQ_RESET` al SIS. SIS BLOQUEADO ⇒ se queda en FALLA(13) |

Reglas generales:
- Tras reinicio o corte: siempre AUTOTEST → LISTO.
- Sin `HMI_HB` > 10 s con un ciclo activo ⇒ ENFRIAMIENTO (se registra el código 12).
- Sin `HB_SIS` > 500 ms ⇒ SSR1 off y FALLA(7).
- La puerta abierta apaga SSR1 de inmediato en el control (redundante con el SIS).

### 8.5 Perfiles [hipótesis, POR MEDIR en F9]

`setpoint` en °C del aire de recámara (TC1):

| `shoe_id` | Suave | Media | Intensa |
|---|---|---|---|
| 0 Cuero | 35 | 40 | 45 |
| 1 Deportivo | 40 | 45 | 50 |
| 2 Bota | 40 | 45 | 50 |
| 3 Sintético | 38 | 42 | 48 |

Duración del tratamiento: Corta 5 min, Media 10 min, Larga 25 min. Tope global de ciclo: 120 min.

### 8.6 Control de temperatura y actuadores
- **Etapa 1 (F5)**: histéresis sobre TC1 (encender si < setpoint − 0,5 °C; apagar si > setpoint + 0,5 °C) con un mínimo de 5 s encendido o apagado.
- **Etapa 2 (F9)**: PI con salida 0–100 % y ventana proporcional de 2 s (mínimo 100 ms on/off), anti-windup por saturación. Ganancias [POR MEDIR].
- **Arranque suave del PTC** [PROPUESTA, sólo si F7 muestra que el arranque hace caer la fuente]: limitar el ciclo de trabajo durante los primeros 20 s.
- **Límites de proceso**:
  - TC2 > TC2_MAX_C ⇒ salida a 0 hasta que baje de TC2_RESUME_C.
  - TC1 > setpoint + SOFT_OVERTEMP_MARGIN_C ⇒ FALLA(6) (retira `heat_request`: el SIS abre RL1).
- **FAN_P**: nunca pedir su apagado con `heat_request = 1`, SSR1 activo o TC2 ≥ T_FRIO.
- La salida de SSR1 sólo se activa con `heat_request = 1`, la puerta cerrada y `HB_SIS` indicando permiso concedido (`io_flags` b2).

### 8.7 Consola de servicio y registro (USB de la placa de control, UART0)
- **CSV a 1 Hz** durante los ciclos (o siempre, con `log on`):
  `t_ms,state,sp,tc1,tc2,tc3,rh,voc,ssr1,permit,fan_c,fan_p_off,door,sis_state,trip_mask,fault`
- Comandos de texto: `status`, `log on|off`, `servicio desbloquear` (§7.9).
- Pendiente para F7: comando `duty <0-100>` de control manual, sólo en una compilación de ensayo.

---

## 9. Firmware del HMI (ESP32-32E)

Plan detallado: [firmware/hmi/PLAN.md](../firmware/hmi/PLAN.md). Resumen:
- LVGL 9 + LovyanGFX, PlatformIO, pantalla en horizontal (320 × 240).
- Zonas táctiles ≥ 56 px (≈ 11 mm); texto ≥ 20 px; fuentes generadas con acentos.
- Dos tareas de FreeRTOS: `taskUi` (LVGL) y `taskLink` (protocolo de §6). El simulador del control previsto en PLAN.md no se implementó: la pantalla se prueba con el control real.
- **Enlace**: UART2 reasignado a IO25 (TX) / IO32 (RX), `Serial2.begin(115200, SERIAL_8N1, 32, 25)`. Conexión directa al ESP32 DevKit V1 de control (ambos a 3,3 V).
- Pantallas a partir de `STATUS`: `cycle_state` decide la pantalla; `sis_state == BLOQUEADO` ⇒ "Equipo bloqueado"; evento térmico (`trip_mask` b0, b2 o b7) ⇒ "Se detectó sobrecalentamiento. Revisa los ventiladores" con el botón Rearmar; `fault_code` ⇒ textos de §6.5.
- Sin `STATUS` > 2 s ⇒ "Sin comunicación".
- `HMI_HB` cada 500 ms.

---

## 10. Fases de implementación

Estado (2026-10-06): **código de los tres nodos escrito con FreeRTOS; compila; sin probar en hardware.** Siguiente paso: F3 (electrónica de banco) y la puesta en marcha de cada placa. Las fases de abajo se escribieron para la estructura anterior (lógica en `lib/` con pruebas en PC): donde digan "tests `native`" o "lógica en PC", léase "prueba en banco".

Decisiones abiertas aplicadas en el código con la opción recomendada (cambiar si el usuario decide otra cosa): A-4 disparo enclavado (SIF-06), A-5 servicio por consola + 3 aperturas de puerta, A-7 CSV por USB, A-8 nombres propuestos, A-11 opción T1 (el SIS no lee el termostato).

```mermaid
flowchart LR
  F0[F0 Base del repo] --> F1[F1 Prototipo HMI]
  F0 --> F2[F2 Protocolo]
  F0 --> F3[F3 Electrónica de banco]
  F2 --> F4[F4 Firmware SIS - ESP32 Dev Kit]
  F3 --> F4
  F2 --> F5[F5 Firmware control - ESP32 DevKit V1 de control]
  F3 --> F5
  F1 --> F6[F6 Integración de los 3 nodos]
  F4 --> F6
  F5 --> F6
  F6 --> F7[F7 Integración de potencia y caracterización]
  F7 --> F8[F8 Validación del SIS]
  F8 --> F9[F9 Ajuste de perfiles]
  F9 --> F10[F10 Uso y resistencia]
```

F1, F2 y F3 pueden avanzar en paralelo.

### F0 — Base del repositorio
- **Tareas**: `platformio.ini` de los tres proyectos con versiones fijadas; `compartido/qs_protocol.h`; `config.h` de cada nodo.
- **Hecho cuando**: `pio run` compila los tres proyectos. **Hecho.**

### F1 — Prototipo del HMI
- **Tareas**: fases F0–F7 de [PLAN.md](../firmware/hmi/PLAN.md).
- **Depende de**: F0. Decisión A-8.
- **Hecho cuando**: se cumplen los criterios de PLAN.md, incluida la prueba de usabilidad con dedo y stylus.

### F2 — Biblioteca de protocolo
- **Tareas**: enums (§6.5), estructuras (§6.4), CRC16 con su vector, codificador, parser con resincronización, contadores de error.
- **Comprobación**: en banco, con los dos enlaces conectados (los latidos llegan y un cable flojo no cuelga ningún nodo).
- **Hecho cuando**: todas las pruebas pasan.

### F3 — Electrónica de banco (sin PTC)
- **Depende de**: A-11, A-12.
- **Tareas**:
  1. Montar la distribución de §5.2 con **carga ficticia** en lugar del PTC: lámpara automotriz de 12 V/21 W o resistencia de potencia (carga de ensayo, no parte del equipo).
  2. Ajustar REG_A y REG_B a 5,0–5,1 V antes de conectar placas.
  3. Cablear puerta, MAX6675, S1, S2 y los módulos de relé según [pinout/](pinout/README.md).
  4. Comprobar continuidad, polaridad y estrella de tierra.
- **Mediciones y comprobaciones**:
  - 5V_A y 5V_B en vacío y con carga; rizado < 100 mV pico a pico.
  - **Cada módulo de relé y cada SSR se activa con 3,3 V** del ESP32 y **queda desactivado con la entrada al aire** (placa desconectada o arrancando).
  - Ninguna salida se activa durante el arranque de cada ESP32 (pulsos en los pines al encender).
  - Lógica de contactos: FAN_P sólo se apaga con RL2 y RL3 energizados; FAN_C se enciende con SSR2 o RL4.
  - Temperatura del SSR1 con la carga ficticia.
- **Hecho cuando**: todo dentro de lo esperado y anotado en `docs/ensayos/F3.md`.

### F4 — Firmware del SIS (ESP32 Dev Kit)
- **Depende de**: F2, F3, A-4, A-5, A-11.
- **F4a, lógica en PC**: cada SIF con casos que disparan y que no; las 4 combinaciones de la puerta y el antirrebote; TC congelado; pendiente y "calentamiento sin efecto"; persistencia (formato, CRC, 1.er y 2.º evento, corrupción); rearme aceptado y rechazado; "la comunicación sólo restringe" (ningún `HB_CTRL` concede el permiso con condiciones inseguras).
- **F4b, drivers**: MAX6675, salidas, watchdog, NVS, enlace, radios apagadas.
- **F4c, banco**: con RL1, RM1 reales y carga ficticia; medir el tiempo puerta → RL1 con osciloscopio o analizador lógico.
- **Hecho cuando**: respuesta de la puerta < 200 ms medida; el watchdog reinicia ante un bucle infinito forzado (en compilación de prueba).

### F5 — Firmware de control (ESP32 DevKit V1 de control)
- **Depende de**: F2, F3, A-7.
- **F5a**: planificador, drivers de sensores, CSV por USB. Lecturas estables durante 1 h.
- **F5b, lógica en PC**: todas las transiciones de §8.4; pausa de 5 min; tope de 120 min; corte de energía en cada estado; perfiles e ids fuera de rango; prioridad de fallas; reglas de ventiladores.
- **F5c**: SSR1, SSR2 y RL2 con cargas ficticias; ventana del SSR.
- **F5d**: enlace con el SIS (heartbeats, permiso, rearme) y comandos `hmi` de la consola para probar sin pantalla.
- **Hecho cuando**: un ciclo completo con carga ficticia recorre todos los estados y las fallas inyectadas se manejan como en §8.4.

### F6 — Integración de los tres nodos
- **Tareas**: cableado de §5.7; pruebas de pérdida de cada enlace (desconectar cables durante el ciclo).
- **Hecho cuando**: un ciclo se controla entero desde la pantalla con carga ficticia y cada pérdida de enlace produce la reacción de §5.10.

### F7 — Integración de potencia y caracterización (con PTC real, sin calzado)
- **Seguridad durante los ensayos**: siempre con supervisión; PTC sobre superficie no inflamable; extintor a mano; ciclo de trabajo limitado (comando `duty`, pendiente de escribir); `T_SIS_MAX` provisional bajo (55 °C) hasta conocer las temperaturas normales.
- **Mediciones**:
  1. Corriente de arranque del PTC (pinza DC o shunt + osciloscopio) y si la fuente de 20 A la soporta; decidir el arranque suave.
  2. Temperatura de RL1, TH1 y SSR1 a 8,3 A durante 30 min.
  3. Curvas TC1/TC2/TC3 con ciclos de trabajo del 25, 50 y 100 % y ventiladores normales ⇒ **TC3 máxima en operación normal**.
  4. Temperatura de las aletas del PTC y del punto de montaje de TH1: TH1 no debe acercarse a 75 °C en operación normal.
  5. Con FAN_P desconectado y ciclo de trabajo bajo: pendiente de TC3 ⇒ umbral de SIF-03.
  6. Con TH1 abierto (simulado) y SSR1 al 100 %: caída de TC3 ⇒ parámetros de SIF-08.
  7. Temperatura interior de la cámara de circuitos tras 1 h.
- **Resultado**: valores de T_SIS_MAX, SIF-03, SIF-08, TC2_MAX y posiciones definitivas de TC3/TH1/S2, anotados en `docs/ensayos/F7.md` y en la §12.

### F8 — Validación del SIS
- **Tareas**: V-01 … V-13 de [seguridad-sis.md](seguridad-sis.md) en el equipo integrado, más SSR1 en corto (puenteado).
- **Hecho cuando**: todas pasan; tiempos de respuesta anotados en `docs/ensayos/F8.md`. **Repetir F8 tras cualquier cambio del firmware del SIS o de la versión del core.**

### F9 — Ajuste de perfiles
- **Tareas**: ajuste del PI; las 36 combinaciones con calzado de prueba (TC1 dentro de ±2 °C del setpoint en tratamiento, sin sobrepasar el límite); duraciones; curvas de VOC/HR con calzado real ⇒ decisión A-6.
- **Hecho cuando**: tabla de perfiles definitiva en `profiles.cpp` y en §8.5.

### F10 — Uso y resistencia
- **Tareas**: prueba de usabilidad en el equipo real; 20 ciclos consecutivos; corte de energía en cada estado; 4 h continuas de funcionamiento; revisión visual del cableado (no hay fusibles).
- **Hecho cuando**: sin fallas no explicadas; versión 1.0 etiquetada en git.

---

## 11. Pruebas (resumen)

| Nivel | Qué | Dónde | Fase |
|---|---|---|---|
| HMI | Pantallas con simulador | ESP32-32E | F1 |
| Banco eléctrico | Reguladores, activación con 3,3 V, estado con la entrada al aire, lógica de contactos | Banco | F3 |
| Integración | Enlaces y fallas de enlace | Banco | F6 |
| Caracterización | Temperaturas, corrientes | Equipo | F7 |
| Validación del SIS | Inyección de fallas | Equipo | F8 |
| Perfiles | 36 combinaciones | Equipo | F9 |
| Resistencia y uso | Ciclos repetidos, personas | Equipo | F10 |

---

## 12. Tabla maestra de parámetros

Los nombres son los que debe usar el código.

**Compartidos (`qs_protocol.h`)**

| Constante | Valor | Estado |
|---|---|---|
| `QS_PROTO_VERSION` | 1 | [PROPUESTA] |
| `QS_BAUD_CTRL_SIS`, `QS_BAUD_CTRL_HMI` | 115200 | [PROPUESTA] |
| `QS_MAX_PAYLOAD` | 32 | [PROPUESTA] |
| `HB_PERIOD_MS` | 100 | [PROPUESTA] |
| `HB_SIS_TIMEOUT_MS` (lo usa el control) | 500 | [PROPUESTA] |
| `HB_CTRL_TIMEOUT_MS` (lo usa el SIS) | 2000 | [PROPUESTA] |
| `STATUS_PERIOD_MS` | 200 | [PROPUESTA] |
| `STATUS_TIMEOUT_MS` (lo usa el HMI) | 2000 | [PROPUESTA] |
| `HMI_HB_PERIOD_MS` | 500 | [PROPUESTA] |
| `HMI_LINK_TIMEOUT_MS` (lo usa el control) | 10000 | [PROPUESTA] |

**SIS (`sis/src/config.h`)** — el código usa estos valores; algunos nombres se abreviaron o llevan la unidad en el nombre (`_MS`, `_Q2`)

| Constante | Valor | Estado |
|---|---|---|
| `SIS_LOOP_MS` | 10 | [PROPUESTA] |
| `SIS_WDT_MS` | 1000 (Task Watchdog) | [PROPUESTA] |
| `TC3_PERIOD_MS` | 250 | [PROPUESTA] |
| `T_SIS_MAX_Q2` | 272 (68 °C); 220 (55 °C) durante F7 | [POR MEDIR] F7 |
| `T_SIS_RESET_Q2` | 180 (45 °C) | [PROPUESTA] |
| `T_FRIO_Q2` | 140 (35 °C) | [PROPUESTA] |
| `TC3_MIN_VALID_Q2` / `TC3_MAX_VALID_Q2` | −40 (−10 °C) / 600 (150 °C) | [PROPUESTA] |
| `TC3_BAD_READS` | 3 | [PROPUESTA] |
| `TC3_FROZEN_MS` | 60000 | [PROPUESTA] |
| `DOOR_DEBOUNCE_MS` | 30 | [PROPUESTA] |
| `SIF03_SLOPE_Q2_10S` | 40 (10 °C en 10 s) | [POR MEDIR] F7 |
| `SIF07_MAX_HEAT_MIN` | 125 | [PROPUESTA] |
| `SIF07_COOL_OFF_MIN` | 10 | [PROPUESTA] |
| `SIF08_WINDOW_S` / `SIF08_DUTY_PCT` / `SIF08_DROP_Q2` | 60 / 80 / 12 (3 °C) | [POR MEDIR] F7 |
| `FAN_P_OFF_HOLD_S` | 60 | [PROPUESTA] |
| `THERMAL_EVENTS_LOCKOUT` | 2 | [DECIDIDO] |
| `SERVICE_DOOR_TOGGLES` / `SERVICE_WINDOW_MS` | 3 / 30000 | [ABIERTO A-5] |

**Control (`control/src/config.h`)** — ídem (`_MS`, `_X10`)

| Constante | Valor | Estado |
|---|---|---|
| `CTRL_WDT_MS` | 2000 (Task Watchdog) | [PROPUESTA] |
| `TC_READ_PERIOD_MS` | 250 (alternando TC1/TC2) | [PROPUESTA] |
| `SSR_WINDOW_MS` / `SSR_MIN_ON_MS` | 2000 / 100 | [PROPUESTA] |
| `HYST_X10` / `HYST_MIN_STATE_MS` | 5 (0,5 °C) / 5000 | [PROPUESTA] |
| `PI_KP`, `PI_TI_S` | — | [POR MEDIR] F9 |
| `SOFT_OVERTEMP_MARGIN_C` | 5 | [PROPUESTA] |
| `TC2_MAX_C` / `TC2_RESUME_C` | 70 / 65 | [POR MEDIR] F7 |
| `TREAT_BAND_C` | 3 | [PROPUESTA] |
| `PREHEAT_TIMEOUT_MIN` | 15 | [PROPUESTA] |
| `PAUSE_MAX_S` | 300 | [CONFIRMADO] |
| `CYCLE_MAX_MIN` | 120 | [PROPUESTA] |
| `COOL_END_TC1_C` / `COOL_END_TC2_C` / `COOL_MAX_MIN` | 35 / 40 / 15 | [PROPUESTA] |
| `T_FRIO_C` / `FAN_OFF_HOLD_S` | 35 / 60 | [PROPUESTA] |
| `SIS_BOOT_WAIT_MS` | 5000 | [PROPUESTA] |
| Tabla de perfiles | §8.5 | [POR MEDIR] F9 |

**HMI**: ver [PLAN.md](../firmware/hmi/PLAN.md) (tamaños, colores, fuentes) y [pinout/esp32-hmi.md](pinout/esp32-hmi.md).

---

## 13. Riesgos principales

| Riesgo | Impacto | Mitigación | Fase |
|---|---|---|---|
| **Sin fusibles** [CONFIRMADO] | Un cortocircuito en un cable fino (ventiladores, reguladores, módulos) lo calienta antes de que actúe la protección de la fuente de 20 A: riesgo de incendio | Riesgo aceptado por el usuario. 12 AWG en la rama principal y del PTC; cables finos cortos, sujetos y lejos de material inflamable; revisión visual | F3, F10 |
| El SIS no lee nodos de 12 V | Termostato (T1), RL1 soldado, SSR1 en corto y tensión de FAN_P sin medición directa | TC3 junto a TH1; SIF-01/03/08; reacción del control; opciones A-11 (T2) y A-12 | F7, F8 |
| Módulos que no se activan con 3,3 V | Un relé o SSR que no responde | Elegir módulos compatibles con 3,3 V; comprobar en F3 | F3 |
| Módulos que no quedan desactivados con la entrada al aire o pines que pulsan al arrancar | Permiso o ventilador en estado inesperado durante el arranque | Pines sin comportamiento de arranque (ver pinouts); comprobar en F3 | F3 |
| Temperatura de las aletas del PTC muy por encima de 80 °C en uso normal | TH1 y SIF-01 dispararían sin falla | Montar TC3/TH1 en el aire de salida, no en las aletas; medir | F7 |
| Corriente de arranque del PTC desconocida | Fuente en protección o contacto de RL1 o TH1 dañado | Medir; arranque suave por firmware; RL1 de 30 A | F7 |
| SSR genérico sobrevalorado | Sobrecalentamiento, falla en corto | SSR ≥ 40 A con disipador; medir temperatura; RL1 en serie | F3, F7 |
| SGP40 fuera de su rango de temperatura | Lecturas erróneas o degradación | Montarlo en la zona fresca; verificar la hoja de datos | F7 |
| Los tres controladores son Espressif con el mismo toolchain | Falla de causa común | SIS mínimo, sin radio ni bibliotecas de terceros; validación tras cambios de versión del core | F4, F8 |
| Ventiladores sin tacómetro | Ventilador trabado sin detección directa | SIF-03, TC2_MAX, TH1 | F7, F8 |
| Un solo termostato, de rearme automático | Punto único de falla en la capa 3 | Enclavado del SIS por eventos térmicos | F8 |
| Sin paro físico | El usuario no puede parar si falla la pantalla | La puerta corta; RD-03; tope de ciclo | F8 |
| Que una futura modificación mueva funciones entre control y SIS | Rompe la regla de máxima prioridad | ADR-0012; revisar cada cambio contra §0.2 | Siempre |

---

## 14. Registro de decisiones (resumen de los ADR)

| ADR | Decisión | Estado |
|---|---|---|
| **0012** | **Control y SIS en controladores separados, estrictamente** (hoy: ESP32 DevKit V1 de control y ESP32 Dev Kit) | [CONFIRMADO], prioridad máxima |
| **0013** | **Sólo módulos y dispositivos**; sin optoacopladores, convertidores de nivel ni fusibles | [CONFIRMADO] |
| 0001 | Control y SIS en MCU independientes | [DECIDIDO] |
| 0002 | Control en ESP32 DevKit V1 de control, SIS en ESP32 Dev Kit | [CONFIRMADO] |
| 0003 | (Retirada; reemplazada por la 0010) | — |
| 0004 | TC1/TC2 al control, TC3 exclusivo del SIS | [PROPUESTA] |
| 0005 | Pantalla ESP32 como nodo HMI sólo de comunicación | [CONFIRMADO] |
| 0006 | Producto doméstico sin paro físico | [CONFIRMADO] |
| 0007 | Perfiles en el control; SIS con límite único | [PROPUESTA] |
| 0008 | Termostato: enclavado persistente, bloqueo tras 2 eventos; cableado T1/T2 | [DECIDIDO]; [ABIERTO A-11] |
| 0009 | FAN_P: relé del control y relé de veto del SIS con contactos NC en paralelo | [DECIDIDO] |
| 0010 | Permiso del PTC con un módulo de relé en serie | [DECIDIDO] |
| 0011 | Sin componentes auxiliares (versión que movía los ventiladores al SIS) | **Revocada** |

---
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

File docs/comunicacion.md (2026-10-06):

# Comunicación entre nodos

Resumen. El formato byte a byte de la trama y de cada mensaje está en [PLAN-MAESTRO §6](PLAN-MAESTRO.md#6-firmware-común). Contrato de código en `firmware/compartido/qs_protocol.h` (única fuente de verdad, incluido por los tres firmwares).

## Enlaces

Los tres controladores trabajan a 3,3 V: **cables directos**, sin convertidores.

| Enlace | Puertos | Notas |
|---|---|---|
| Control ↔ SIS | Control UART2 (GPIO17 TX / GPIO16 RX) ↔ SIS UART2 (GPIO16 RX / GPIO17 TX), cruzados | La depuración de cada placa va por su USB |
| Control ↔ HMI | Control UART1 reasignado (GPIO4 TX / GPIO35 RX) ↔ HMI UART2 reasignado a IO32 (RX) / IO25 (TX), en el conector I2C de la placa | UART0 del HMI queda libre para depurar por USB |

Velocidad: **115200 8N1** en ambos enlaces. GND común entre los tres nodos. El HMI no habla con el SIS. Pines exactos: [pinout/](pinout/README.md).
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

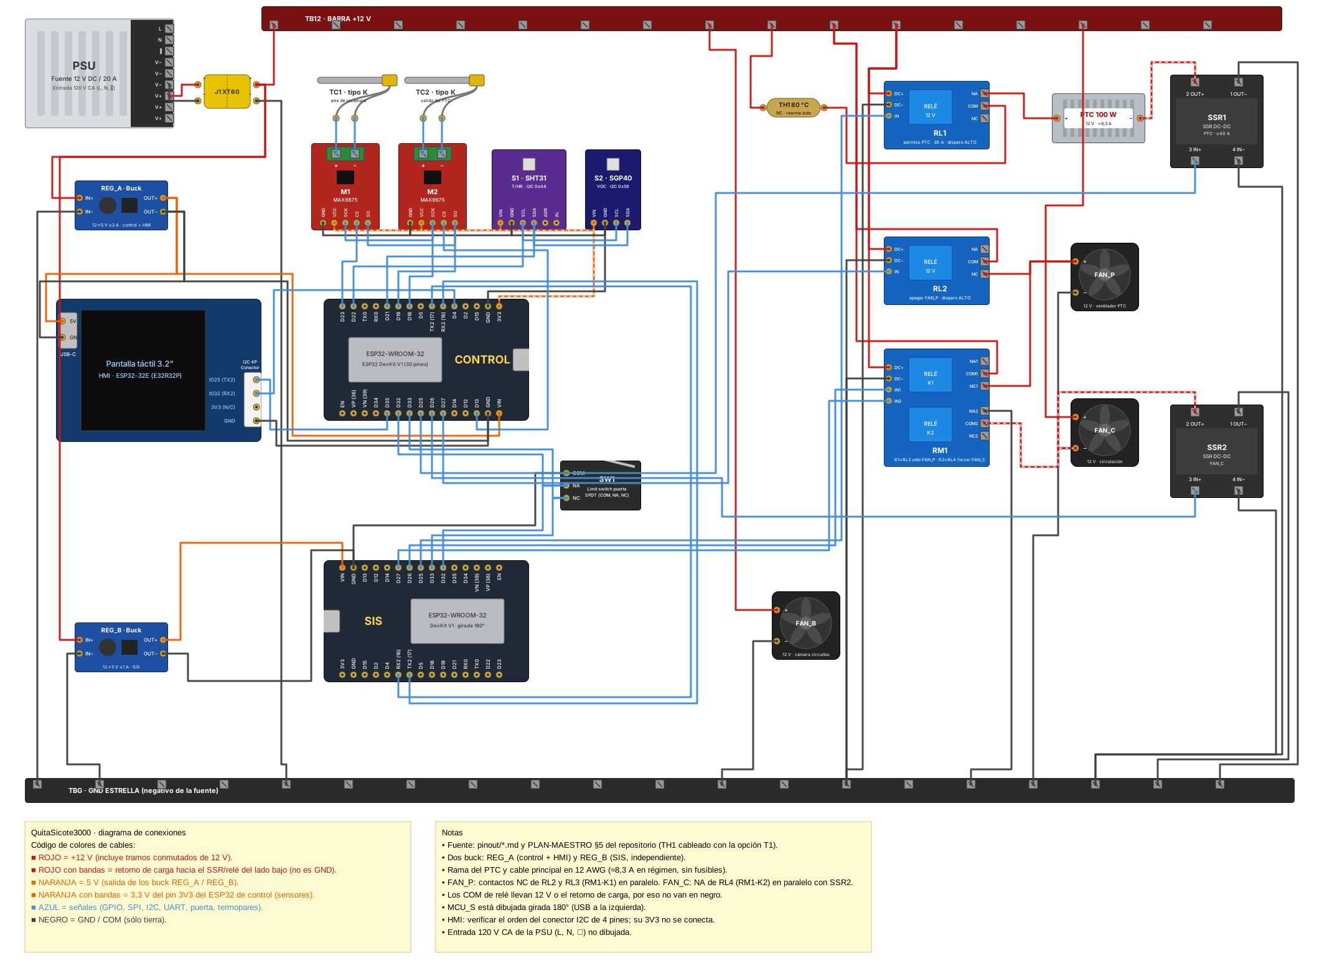
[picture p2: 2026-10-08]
hardware/fritzing/QuitaSicote3000_conexiones_preview.png

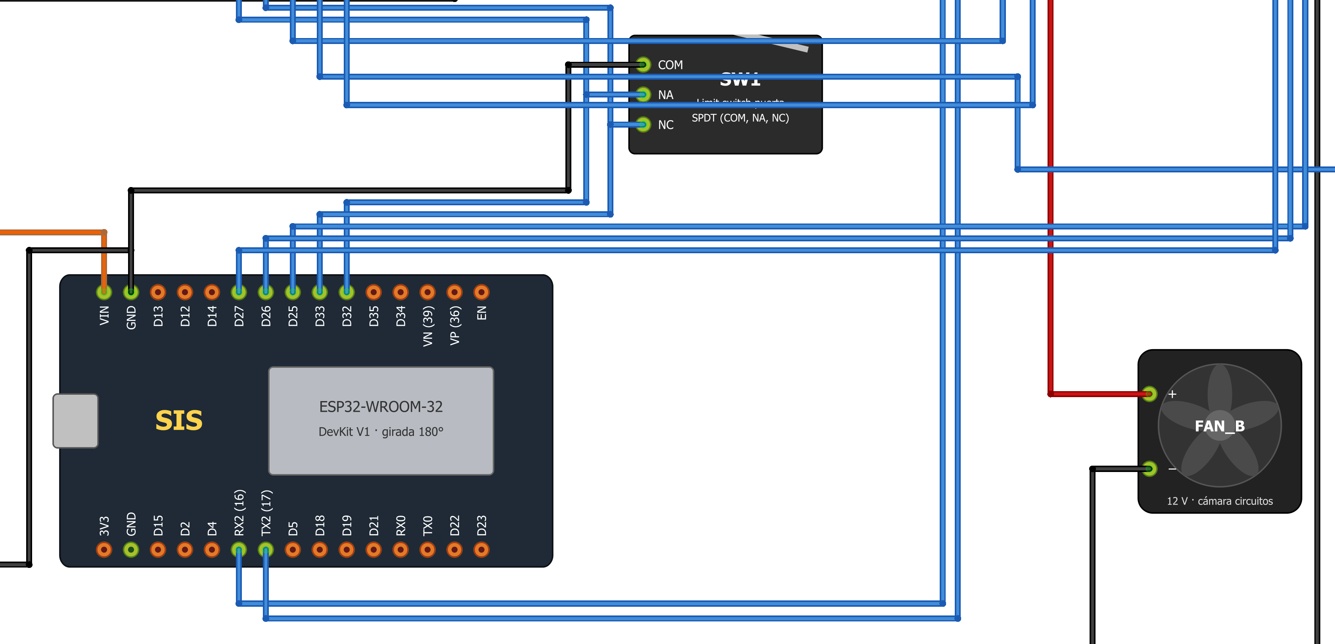
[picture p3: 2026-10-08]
docs/guia-de-conexion/zona3-sis-y-puerta.png

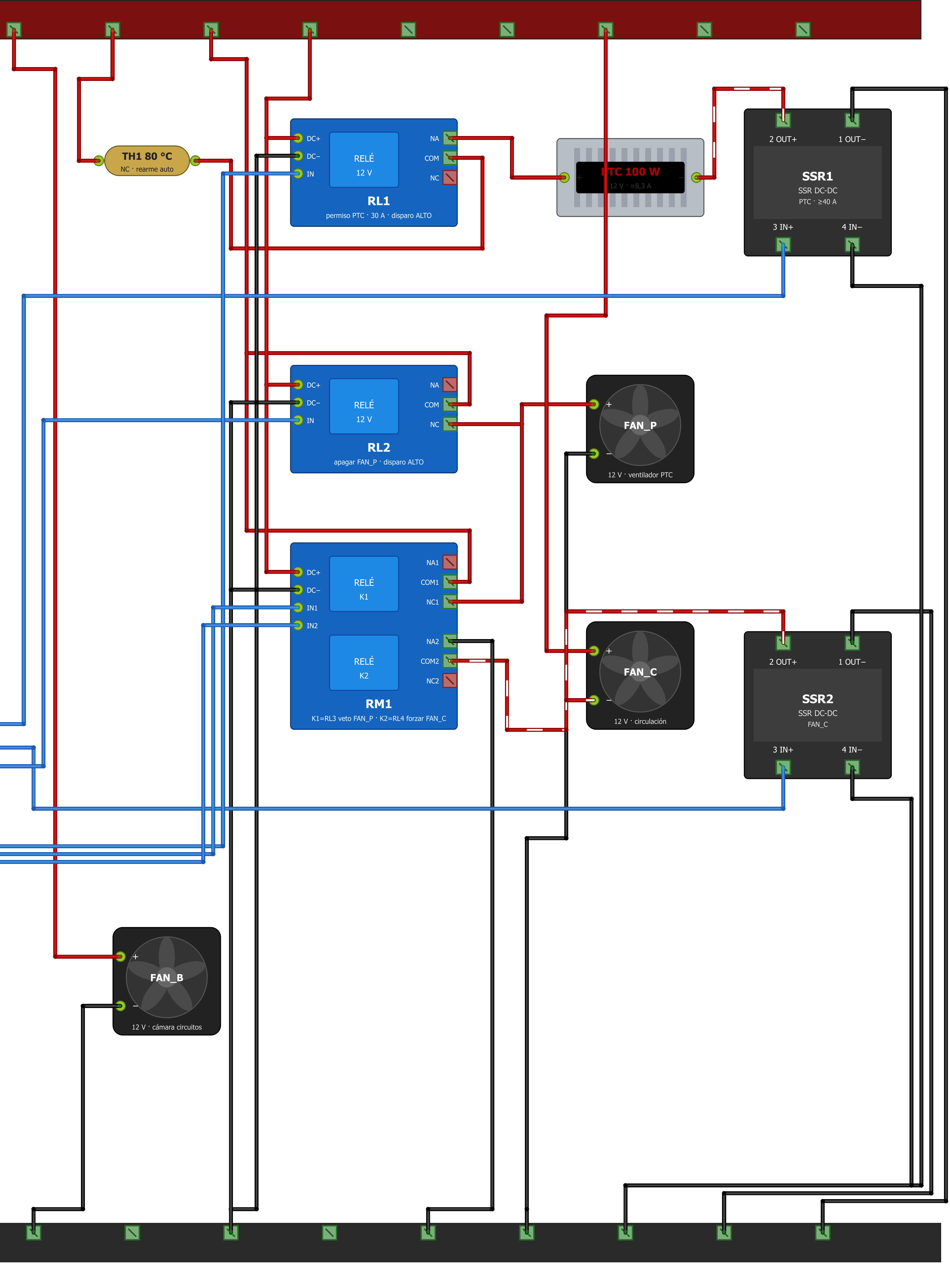
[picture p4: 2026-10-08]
docs/guia-de-conexion/zona4-cargas.png

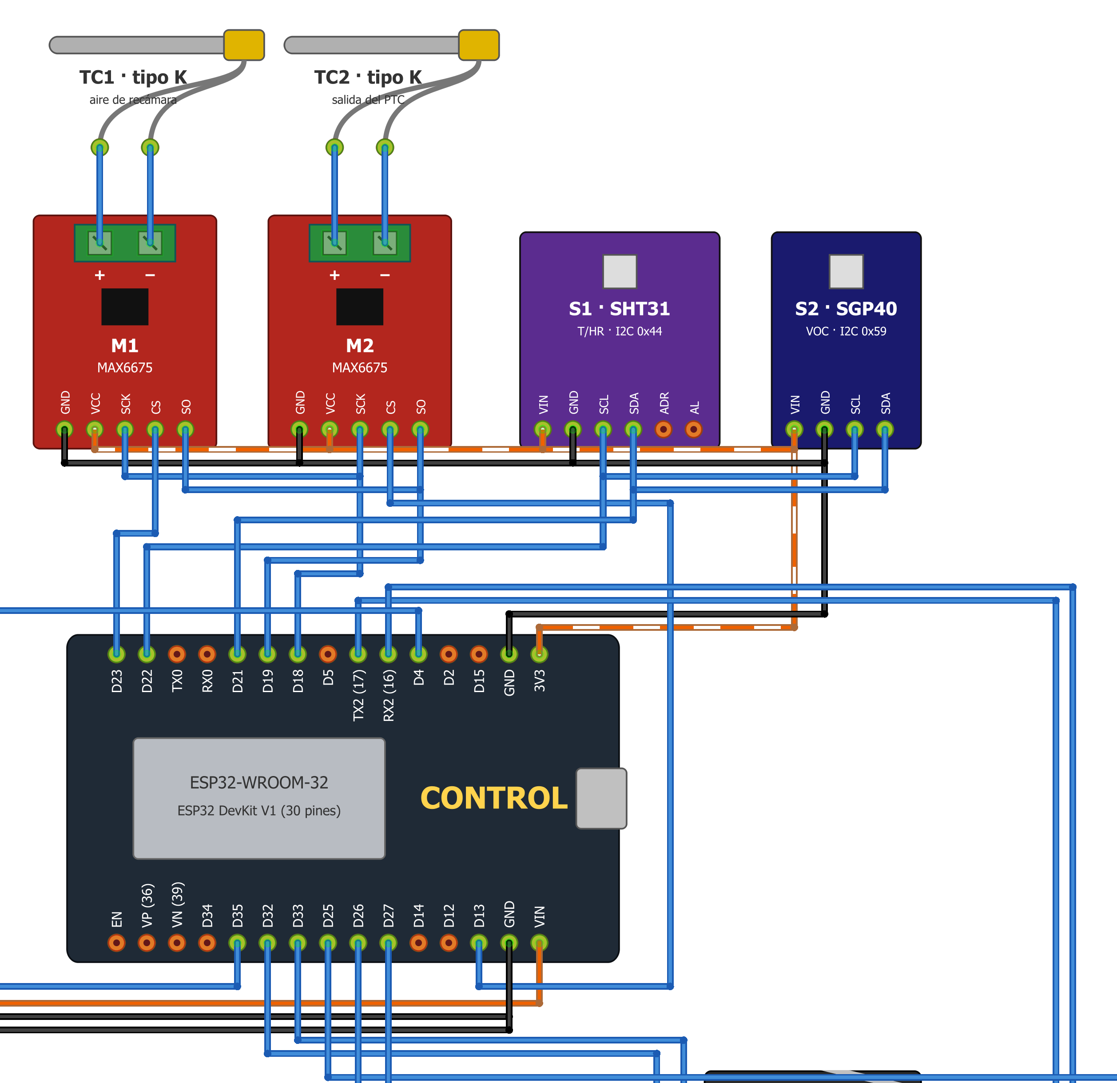
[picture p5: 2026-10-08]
docs/guia-de-conexion/zona2-control-y-sensores.png

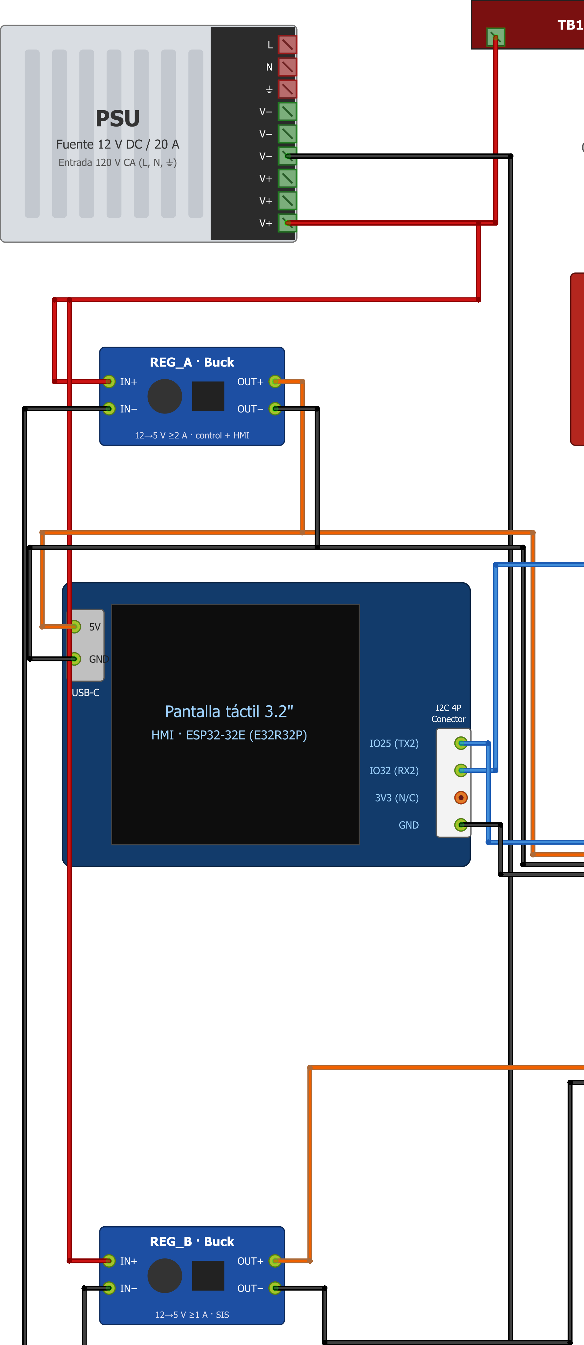
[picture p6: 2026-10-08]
docs/guia-de-conexion/zona1-fuente-y-reguladores.png

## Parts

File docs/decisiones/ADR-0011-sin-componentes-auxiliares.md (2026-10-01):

# ADR-0011 — Sin componentes auxiliares pequeños

**Estado:** **Revocada** por el usuario (2026-09-30). Sustituida por la ADR-0012.

## Qué decía
No usar compuertas, transistores, diodos, resistencias ni fusibles sueltos.

## Por qué se revocó
Sin compuertas, la única forma de que el SIS conservara la capacidad de vetar el apagado del ventilador del PTC y de forzar el de circulación era que el Nano manejara los ventiladores. Eso convertía al Nano en controlador de proceso, en contra de la regla de máxima prioridad de la ADR-0012: **control = Mega, SIS = Nano**.

## Relación con la ADR-0013
La preferencia del usuario por usar sólo módulos y dispositivos se recoge en la [ADR-0013](ADR-0013-solo-modulos-y-dispositivos.md), que la resuelve **sin** mover funciones entre la Mega y el Nano: la lógica AND/OR se hace con contactos de módulos de relé y el sensado con un módulo optoacoplador.

## Lo que sigue vigente de esa etapa
- Dos reguladores de 5 V independientes (decisión del usuario, se mantiene).
- El permiso del PTC con un módulo de relé (ADR-0010, se mantiene).

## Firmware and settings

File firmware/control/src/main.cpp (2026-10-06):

// =============================================================================
//  QuitaSicote3000 — CONTROL · ESP32 DevKit V1
// =============================================================================
//  Este controlador hace SÓLO control (ADR-0012): lleva el ciclo de
//  tratamiento, regula la temperatura y maneja los ventiladores. La seguridad
//  la hace el SIS, en otra placa.
//
//  Salidas:  SSR1 (calentar el PTC) · SSR2 (ventilador de circulación, FAN_C)
//            RL2 (pedir que se apague el ventilador del PTC, FAN_P)
//  Entradas: TC1 (recámara) · TC2 (salida del PTC) · SHT31 · SGP40 · puerta
//
//  Cinco tareas de FreeRTOS:
//
//    taskCycle     cada 10 ms    puerta -> máquina de estados -> salidas
//    taskSensors   cada 250 ms   termopares; una vez por segundo, humedad y olor
//    taskSisLink   cada 10 ms    recibe HB_SIS, envía HB_CTRL y los rearmes
//    taskHmiLink   cada 10 ms    recibe las solicitudes de la pantalla, envía STATUS
//    taskConsole   cada 100 ms   comandos por USB y registro CSV
//
//  Todas comparten las variables de la sección "Estado compartido", siempre
//  con el mutex tomado (ver la clase Lock).
// =============================================================================
#include <Arduino.h>
#include <VOCGasIndexAlgorithm.h>
#include <esp_task_wdt.h>

#include "config.h"
#include "qs_protocol.h"
#include "sensors.h"

using namespace qs;

// =============================================================================
//  Estado compartido entre las tareas
// =============================================================================

SemaphoreHandle_t stateMutex;

// Toma el mutex al crearse y lo suelta al salir del bloque:
//     { Lock lock;  ...leer o escribir el estado compartido...  }
struct Lock {
  Lock() { xSemaphoreTake(stateMutex, portMAX_DELAY); }
  ~Lock() { xSemaphoreGive(stateMutex); }
};

// --- Lecturas de los sensores (las escribe taskSensors) ---
struct Readings {
  bool tc1Valid = false;        // TC1: aire de la recámara
  bool tc2Valid = false;        // TC2: salida del PTC
  int16_t tc1X10 = 0;           // décimas de grado
  int16_t tc2X10 = 0;
  bool humidityValid = false;   // SHT31
  int16_t ambientX10 = 250;
  uint16_t humidityX10 = 500;   // décimas de %
  bool vocValid = false;        // SGP40
  bool vocLearning = true;      // el índice de olor aún se está estabilizando
  uint16_t vocIndex = 0;
} readings;

// --- Lo que informa el SIS (lo escribe taskSisLink) ---
struct SisInfo {
  bool seen = false;            // llegó al menos un HB_SIS
  uint32_t lastHeartbeatMs = 0;
  uint32_t bootSinceMs = 0;     // desde cuándo dice estar arrancando
  SisState state = SisState::Boot;
  uint16_t tripMask = 0;
  uint8_t ioFlags = 0;
  uint8_t thermalEvents = 0;
} sis;

// --- El ciclo de tratamiento (lo escribe taskCycle; taskHmiLink hace solicitudes) ---
struct Cycle {
  CycleState state = CycleState::SelfTest;
  uint32_t stateSinceMs = 0;
  uint8_t faultCode = FAULT_NONE;

  uint8_t shoe = ID_NONE;       // perfil elegido
  uint8_t intensity = ID_NONE;
  uint8_t duration = ID_NONE;
  int16_t setpointX10 = 0;      // temperatura objetivo de TC1
  uint32_t durationMs = 0;      // tiempo de tratamiento pedido
  uint32_t treatedMs = 0;       // tiempo de tratamiento ya cumplido
  uint32_t startedMs = 0;       // cuándo empezó el ciclo (para el tope global)

  PauseReason pauseReason = PauseReason::None;
  bool finishedNormally = false;  // el enfriamiento termina en COMPLETO (si no, en LISTO)
  bool rearmSent = false;         // en FALLA: ya se pidió rearmar el SIS
} cycle;

// --- Entradas y salidas del control ---
Door door = Door::Invalid;
bool ssr1On = false;            // SSR1: calentando
bool fanCOn = true;             // SSR2: ventilador de circulación
bool fanPOffRequest = false;    // RL2: se pide apagar el ventilador del PTC

// --- Enlace con el HMI ---
bool hmiSeen = false;
uint32_t lastHmiHeartbeatMs = 0;

// --- Encargos para taskSisLink ---
bool resetRequested = false;          // enviar REQ_RESET (rearme)
bool serviceUnlockRequested = false;  // enviar REQ_SERVICE (desbloqueo)

// --- Preguntas frecuentes sobre el estado (llamar con el mutex tomado) ---

bool sisAlive(uint32_t now) { return sis.seen && now - sis.lastHeartbeatMs <= HB_SIS_TIMEOUT_MS; }
bool sisIsOk(uint32_t now) { return sisAlive(now) && sis.state == SisState::Ok; }
bool sisGivesPermit(uint32_t now) { return sisAlive(now) && (sis.ioFlags & SIS_IO_PTC_PERMIT); }
bool hmiAlive(uint32_t now) { return hmiSeen && now - lastHmiHeartbeatMs <= HMI_LINK_TIMEOUT_MS; }

bool isHeating() {
  return cycle.state == CycleState::Preheat || cycle.state == CycleState::Treatment;
}
bool cycleInProgress() { return isHeating() || cycle.state == CycleState::Paused; }

// =============================================================================
//  Fallas
// =============================================================================

// Devuelve la falla más importante que está presente ahora mismo, o FAULT_NONE.
// El orden de las comprobaciones es el orden de importancia.
uint8_t activeFault(uint32_t now) {
  const bool alive = sisAlive(now);

  if (alive && sis.state == SisState::Locked) return FAULT_LOCKOUT;
  if (alive && sis.state == SisState::Tripped) return FAULT_SIS_TRIP;
  if (door == Door::Invalid) return FAULT_DOOR_INVALID;
  if (!alive) return FAULT_SIS_NO_LINK;

  // Un SIS que dice estar arrancando se tolera unos segundos, salvo calentando.
  if (sis.state == SisState::Boot) {
    const bool tooLong = now - sis.bootSinceMs >= SIS_BOOT_WAIT_MS;
    if (isHeating() || tooLong) return FAULT_SIS_NO_LINK;
  }

  if (!readings.tc1Valid) return FAULT_TC1_INVALID;
  if (!readings.tc2Valid) return FAULT_TC2_INVALID;
  return FAULT_NONE;
}

// =============================================================================
//  Cambios de estado
// =============================================================================

void enterState(CycleState newState, uint32_t now) {
  cycle.state = newState;
  cycle.stateSinceMs = now;
  if (newState != CycleState::Paused) cycle.pauseReason = PauseReason::None;
}

void enterReady(uint32_t now) {
  cycle.shoe = cycle.intensity = cycle.duration = ID_NONE;
  cycle.faultCode = FAULT_NONE;
  cycle.treatedMs = 0;
  enterState(CycleState::Ready, now);
}

void enterPause(PauseReason reason, uint32_t now) {
  enterState(CycleState::Paused, now);
  cycle.pauseReason = reason;
}

// finishedNormally: el tratamiento se completó (acabará en COMPLETO).
// Si fue una cancelación o una falla, tras enfriar se vuelve a LISTO.
void enterCooling(bool finishedNormally, uint32_t now) {
  cycle.finishedNormally = finishedNormally;
  enterState(CycleState::Cooling, now);
}

void enterFault(uint8_t faultCode, uint32_t now) {
  cycle.faultCode = faultCode;
  cycle.rearmSent = false;
  enterState(CycleState::Fault, now);
}

// =============================================================================
//  Solicitudes del HMI
// =============================================================================
//  La pantalla sólo pide; aquí se decide. Todas se llaman con el mutex tomado.

uint8_t requestStart(const ReqStart& request, uint32_t now) {
  const bool validIds = request.shoe_id < SHOE_COUNT && request.intensity_id < INTENSITY_COUNT &&
                        request.duration_id < DURATION_COUNT;
  if (!validIds) return START_INVALID_ID;
  if (cycle.state == CycleState::Fault) return START_FAULT_ACTIVE;
  if (cycle.state != CycleState::Ready || !sisIsOk(now)) return START_NOT_READY;
  if (door != Door::Closed) return START_DOOR_OPEN;

  cycle.shoe = request.shoe_id;
  cycle.intensity = request.intensity_id;
  cycle.duration = request.duration_id;
  cycle.setpointX10 = SETPOINT_C[request.shoe_id][request.intensity_id] * 10;
  cycle.durationMs = DURATION_MIN[request.duration_id] * 60000u;
  cycle.treatedMs = 0;
  cycle.startedMs = now;
  enterState(CycleState::Preheat, now);
  return START_OK;
}

void requestPause(uint32_t now) {
  if (isHeating()) enterPause(PauseReason::User, now);
}

// Cerrar la puerta no basta para seguir: hace falta esta solicitud.
void requestResume(uint32_t now) {
  if (cycle.state == CycleState::Paused && door == Door::Closed && sisIsOk(now)) {
    enterState(CycleState::Preheat, now);  // conserva el tiempo de tratamiento ya cumplido
  }
}

void requestCancel(uint32_t now) {
  if (cycleInProgress()) enterCooling(false, now);
}

// "Aceptar": en COMPLETO vuelve a LISTO; en FALLA sólo vale con la causa resuelta.
void requestAck(uint32_t now) {
  if (cycle.state == CycleState::Complete) enterReady(now);
  if (cycle.state == CycleState::Fault && activeFault(now) == FAULT_NONE) enterCooling(false, now);
}

// "Rearmar": se le pide al SIS, que es quien decide si se puede.
void requestRearm(uint32_t now) {
  if (cycle.state == CycleState::Fault && sisAlive(now) && sis.state == SisState::Tripped) {
    cycle.rearmSent = true;
    resetRequested = true;
  }
}

// =============================================================================
//  Máquina de estados del ciclo
// =============================================================================
//
//   AUTOTEST -> LISTO -> PRECALENTAMIENTO -> TRATAMIENTO -> ENFRIAMIENTO -> COMPLETO -> LISTO
//                              ^      \          /
//                              |       v        v
//                              +----- PAUSA (máx. 5 min)
//
//   Desde cualquier estado, una falla lleva a FALLA. Tras aceptarla: ENFRIAMIENTO -> LISTO.

// Lo que se comprueba en cada vuelta mientras se calienta.
void heatingStep(uint32_t now, uint32_t elapsed) {
  const uint32_t timeInState = now - cycle.stateSinceMs;
  const bool atTemperature = readings.tc1X10 >= cycle.setpointX10 - TREAT_BAND_X10;

  if (!hmiAlive(now)) {  // sin pantalla nadie puede parar el equipo: se cancela
    Serial.println("[CTRL] sin enlace con el HMI: ciclo cancelado");
    enterCooling(false, now);
  } else if (door != Door::Closed) {
    enterPause(PauseReason::Door, now);
  } else if (now - cycle.startedMs >= CYCLE_MAX_MS) {
    Serial.println("[CTRL] tope de tiempo del ciclo");
    enterCooling(true, now);
  } else if (readings.tc1X10 > cycle.setpointX10 + OVERTEMP_MARGIN_X10) {
    // Al dejar de calentar se retira heat_request y el SIS abre RL1.
    enterFault(FAULT_SOFT_OVERTEMP, now);
  } else if (cycle.state == CycleState::Preheat) {
    if (atTemperature) {
      enterState(CycleState::Treatment, now);
    } else if (timeInState >= PREHEAT_TIMEOUT_MS) {
      enterFault(FAULT_PREHEAT_TIMEOUT, now);
    }
  } else {  // TRATAMIENTO: el tiempo sólo cuenta estando a temperatura
    if (atTemperature) cycle.treatedMs += elapsed;
    if (cycle.treatedMs >= cycle.durationMs) enterCooling(true, now);
  }
}

// Una vuelta de la máquina de estados. Se llama con el mutex tomado.
void cycleStep(uint32_t now, uint32_t elapsed, bool doorJustOpened) {
  const uint32_t timeInState = now - cycle.stateSinceMs;
  const uint8_t fault = activeFault(now);

  // FALLA se trata aparte: es el único estado del que no se sale por otra falla.
  if (cycle.state == CycleState::Fault) {
    if (fault != FAULT_NONE) cycle.faultCode = fault;  // se muestra la causa presente más importante
    // Un rearme que el SIS aceptó cuenta como "falla aceptada".
    if (fault == FAULT_NONE && cycle.rearmSent && sis.state == SisState::Ok) enterCooling(false, now);
    return;
  }

  // AUTOTEST: se da un plazo a los sensores y al SIS para arrancar.
  if (cycle.state == CycleState::SelfTest) {
    const bool sisAlreadyTripped = fault == FAULT_LOCKOUT || fault == FAULT_SIS_TRIP;
    if (fault == FAULT_NONE && sis.state == SisState::Ok) {
      enterReady(now);
    } else if (sisAlreadyTripped || (fault != FAULT_NONE && timeInState >= SIS_BOOT_WAIT_MS)) {
      enterFault(fault, now);
    }
    return;
  }

  // En el resto de estados, cualquier falla presente lleva a FALLA.
  if (fault != FAULT_NONE) {
    enterFault(fault, now);
    return;
  }

  switch (cycle.state) {
    case CycleState::Ready:
      break;  // espera a que el HMI pida iniciar (requestStart)

    case CycleState::Preheat:
    case CycleState::Treatment:
      heatingStep(now, elapsed);
      break;

    case CycleState::Paused:
      if (!hmiAlive(now) || timeInState >= PAUSE_MAX_MS) enterCooling(false, now);
      break;

    case CycleState::Cooling: {
      const bool cool = readings.tc1X10 < COOL_END_TC1_X10 && readings.tc2X10 < COOL_END_TC2_X10;
      if (cool || timeInState >= COOL_MAX_MS) {
        if (cycle.finishedNormally) {
          enterState(CycleState::Complete, now);
        } else {
          enterReady(now);
        }
      }
      break;
    }

    case CycleState::Complete:
      if (doorJustOpened) enterReady(now);  // abrir la puerta equivale a "Aceptar"
      break;

    default:
      break;
  }
}

// =============================================================================
//  Salidas: calefactor y ventiladores
// =============================================================================

// Regulación por histéresis sobre TC1, con tiempo mínimo en cada estado.
void updateHeater(uint32_t now) {
  static bool wanted = false;        // la regulación quiere calor
  static uint32_t changedMs = 0;
  static bool tc2TooHot = false;     // límite de proceso sobre la salida del PTC

  if (!isHeating()) {
    wanted = false;
    tc2TooHot = false;
    ssr1On = false;
    return;
  }

  bool wantNow = wanted;
  if (readings.tc1X10 < cycle.setpointX10 - HYSTERESIS_X10) wantNow = true;
  if (readings.tc1X10 > cycle.setpointX10 + HYSTERESIS_X10) wantNow = false;
  if (wantNow != wanted && now - changedMs >= HEATER_MIN_STATE_MS) {
    wanted = wantNow;
    changedMs = now;
  }

  if (readings.tc2X10 > TC2_MAX_X10) tc2TooHot = true;
  if (readings.tc2X10 < TC2_RESUME_X10) tc2TooHot = false;

  // SSR1 sólo conduce con la puerta cerrada y el permiso del SIS concedido.
  ssr1On = wanted && !tc2TooHot && door == Door::Closed && sisGivesPermit(now);
}

// Los ventiladores están encendidos siempre, salvo en reposo (LISTO o COMPLETO)
// y con el equipo frío desde hace un minuto. FAN_P nunca se apaga calentando.
void updateFans(uint32_t now) {
  static bool coldTimerRunning = false;
  static uint32_t coldSinceMs = 0;

  const bool resting = cycle.state == CycleState::Ready || cycle.state == CycleState::Complete;
  const bool cold = readings.tc2Valid && readings.tc2X10 < COLD_X10;

  if (!resting || !cold) {
    coldTimerRunning = false;
  } else if (!coldTimerRunning) {
    coldTimerRunning = true;
    coldSinceMs = now;
  }
  const bool fansCanStop = coldTimerRunning && now - coldSinceMs >= FAN_OFF_HOLD_MS;

  fanCOn = !fansCanStop;
  fanPOffRequest = fansCanStop;  // el SIS además debe permitirlo con su relé RL3
}

// =============================================================================
//  Tarea del ciclo (10 ms)
// =============================================================================

// Lee la puerta. Cerrada = NA en BAJO y NC en ALTO. Si los dos contactos dicen
// lo mismo (cable cortado, corto, switch dañado) la lectura es inválida.
// Un cambio se acepta tras 30 ms estable.
Door readDoor(uint32_t now) {
  static Door stable = Door::Invalid;
  static Door candidate = Door::Invalid;
  static uint32_t candidateSinceMs = 0;

  const bool noClosed = digitalRead(PIN_DOOR_NO) == LOW;
  const bool ncClosed = digitalRead(PIN_DOOR_NC) == LOW;
  Door reading = Door::Invalid;
  if (noClosed && !ncClosed) reading = Door::Closed;
  if (!noClosed && ncClosed) reading = Door::Open;

  if (reading != candidate) {
    candidate = reading;
    candidateSinceMs = now;
  } else if (now - candidateSinceMs >= DOOR_DEBOUNCE_MS) {
    stable = reading;
  }
  return stable;
}

void taskCycle(void*) {
  esp_task_wdt_add(nullptr);  // si esta tarea se cuelga, el ESP32 se reinicia
  TickType_t wakeTime = xTaskGetTickCount();
  uint32_t previousMs = millis();

  for (;;) {
    {
      Lock lock;
      const uint32_t now = millis();
      const uint32_t elapsed = now - previousMs;
      previousMs = now;

      const Door previousDoor = door;
      door = readDoor(now);
      const bool doorJustOpened = previousDoor == Door::Closed && door == Door::Open;

      cycleStep(now, elapsed, doorJustOpened);
      updateHeater(now);
      updateFans(now);

      digitalWrite(PIN_SSR1, ssr1On);
      digitalWrite(PIN_FAN_C, fanCOn);
      digitalWrite(PIN_FAN_P_OFF, fanPOffRequest);
      digitalWrite(PIN_LED, ssr1On);  // el LED de la placa acompaña al calefactor
    }
    esp_task_wdt_reset();
    vTaskDelayUntil(&wakeTime, pdMS_TO_TICKS(CYCLE_PERIOD_MS));
  }
}

// =============================================================================
//  Tarea de los sensores
// =============================================================================

VOCGasIndexAlgorithm vocAlgorithm;  // algoritmo de Sensirion: señal cruda -> índice 1–500

// Lee un termopar y actualiza su lectura. Una lectura mala suelta se tolera
// (se conserva la anterior); tres seguidas dejan el sensor como inválido.
void updateThermocouple(int csPin, bool& valid, int16_t& valueX10, uint8_t& badReads) {
  int16_t tempX10 = 0;
  const bool readOk = readThermocouple(csPin, tempX10);  // sin el mutex: el SPI tarda

  Lock lock;
  if (readOk) {
    badReads = 0;
    valid = true;
    valueX10 = tempX10;
  } else {
    if (badReads < SENSOR_BAD_READS) badReads++;
    if (badReads >= SENSOR_BAD_READS) valid = false;
  }
}

// Humedad y olor, una vez por segundo.
void updateAirQuality() {
  static uint8_t humidityBadReads = 0;
  static uint8_t vocBadReads = 0;
  static uint16_t vocSamples = 0;

  int16_t ambientX10 = 250;     // sin SHT31, el SGP40 se compensa con 25 °C y 50 %
  uint16_t humidityX10 = 500;
  const bool humidityOk = readSht31(ambientX10, humidityX10);
  uint16_t rawVoc = 0;
  const bool vocOk = readSgp40(ambientX10, humidityX10, rawVoc);
  const int32_t vocIndex = vocOk ? vocAlgorithm.process(rawVoc) : 0;

  Lock lock;
  if (humidityOk) {
    humidityBadReads = 0;
    readings.humidityValid = true;
    readings.ambientX10 = ambientX10;
    readings.humidityX10 = humidityX10;
  } else if (++humidityBadReads >= SENSOR_BAD_READS) {
    humidityBadReads = SENSOR_BAD_READS;
    readings.humidityValid = false;
  }

  if (vocOk) {
    vocBadReads = 0;
    readings.vocValid = true;
    readings.vocIndex = vocIndex;
    if (vocSamples < 60) vocSamples++;
    readings.vocLearning = vocSamples < 60 || vocIndex == 0;  // el primer minuto no es fiable
  } else if (++vocBadReads >= SENSOR_BAD_READS) {
    vocBadReads = SENSOR_BAD_READS;
    readings.vocValid = false;
  }
}

void taskSensors(void*) {
  static uint8_t tc1BadReads = 0;
  static uint8_t tc2BadReads = 0;
  TickType_t wakeTime = xTaskGetTickCount();

  // Cada 250 ms se lee un termopar, alternando (cada uno queda leído cada 500 ms).
  for (uint32_t tick = 0;; tick++) {
    vTaskDelayUntil(&wakeTime, pdMS_TO_TICKS(TC_PERIOD_MS));

    if (tick % 2 == 0) {
      updateThermocouple(PIN_CS_TC1, readings.tc1Valid, readings.tc1X10, tc1BadReads);
    } else {
      updateThermocouple(PIN_CS_TC2, readings.tc2Valid, readings.tc2X10, tc2BadReads);
    }
    if (tick % 4 == 0) updateAirQuality();  // una vez por segundo
  }
}

// =============================================================================
//  Tarea del enlace con el SIS
// =============================================================================

HardwareSerial& sisPort = Serial2;

void handleSisFrame(const Frame& frame) {
  if (frame.type == MSG_HB_SIS) {
    HbSis heartbeat;
    if (!frame.as(heartbeat) || heartbeat.proto_ver != PROTO_VERSION) return;
    if (heartbeat.sis_state > static_cast<uint8_t>(SisState::Locked)) return;

    Lock lock;
    const uint32_t now = millis();
    const SisState newState = static_cast<SisState>(heartbeat.sis_state);
    const bool justEnteredBoot = newState == SisState::Boot && (!sis.seen || sis.state != SisState::Boot);
    if (justEnteredBoot) sis.bootSinceMs = now;

    sis.seen = true;
    sis.lastHeartbeatMs = now;
    sis.state = newState;
    sis.tripMask = heartbeat.trip_mask;
    sis.ioFlags = heartbeat.io_flags;
    sis.thermalEvents = heartbeat.thermal_events;
  } else if (frame.type == MSG_EVENT) {
    SisEventMsg event;
    if (frame.as(event)) {
      Serial.printf("[CTRL] aviso del SIS: evento %u, causas 0x%04X, detalle %u\n", event.event,
                    event.trip_mask, event.detail);
    }
  }
}

// Latido hacia el SIS. heat_request es lo único que el SIS usa para conceder
// el permiso (y sólo si todas SUS condiciones se cumplen).
void sendControlHeartbeat() {
  HbCtrl heartbeat = {};
  {
    Lock lock;
    heartbeat.proto_ver = PROTO_VERSION;
    heartbeat.cycle_state = static_cast<uint8_t>(cycle.state);
    if (isHeating()) heartbeat.ctrl_flags |= CTRL_HEAT_REQUEST;
    if (fanPOffRequest) heartbeat.ctrl_flags |= CTRL_FAN_P_OFF_CMD;
    if (fanCOn) heartbeat.ctrl_flags |= CTRL_FAN_C_CMD;
    if (ssr1On) heartbeat.ctrl_flags |= CTRL_SSR1_CMD;
  }
  sendMessage(sisPort, MSG_HB_CTRL, heartbeat);
}

// Envía al SIS los encargos pendientes: rearme y desbloqueo de servicio.
void sendPendingSisRequests() {
  bool sendReset = false;
  bool sendService = false;
  uint16_t tripMask = 0;
  {
    Lock lock;
    sendReset = resetRequested;
    sendService = serviceUnlockRequested;
    tripMask = sis.tripMask;
    resetRequested = false;
    serviceUnlockRequested = false;
  }
  if (sendReset) {
    ReqReset request = {RESET_MAGIC, tripMask};  // el SIS comprueba que la máscara coincida
    sendMessage(sisPort, MSG_REQ_RESET, request);
  }
  if (sendService) {
    ReqService request = {SERVICE_MAGIC1, SERVICE_MAGIC2, SERVICE_OP_UNLOCK};
    sendMessage(sisPort, MSG_REQ_SERVICE, request);
  }
}
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
void loop() {
  vTaskDelete(nullptr);  // todo ocurre en las tareas: loop() no se usa
}

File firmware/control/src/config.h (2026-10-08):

// =============================================================================
//  Control — Pines, parámetros y perfiles (ESP32 DevKit V1)
// =============================================================================
//  Todo lo que se puede ajustar del control está aquí.
//  Pinout completo: docs/pinout/control-esp32.md · Parámetros: PLAN-MAESTRO §12
//
//  Estos límites son de PROCESO (capa 1). Las funciones de seguridad viven
//  sólo en el SIS.
// =============================================================================
#pragma once
#include <stdint.h>

// ----------------------------- Pines -----------------------------------------
constexpr int PIN_DOOR_NO = 32;    // puerta, contacto NA  (BAJO = contacto cerrado)
constexpr int PIN_DOOR_NC = 33;    // puerta, contacto NC  (BAJO = contacto cerrado)
constexpr int PIN_SSR1 = 25;       // SSR1: ALTO = calentar el PTC
constexpr int PIN_FAN_C = 26;      // SSR2: ALTO = encender el ventilador de circulación
constexpr int PIN_FAN_P_OFF = 27;  // RL2:  ALTO = pedir que se apague el ventilador del PTC
constexpr int PIN_I2C_SDA = 21;    // SHT31 y SGP40
constexpr int PIN_I2C_SCL = 22;
constexpr int PIN_SPI_SCK = 18;    // MAX6675 de TC1 y TC2
constexpr int PIN_SPI_MISO = 19;
constexpr int PIN_CS_TC1 = 23;     // TC1: aire de la recámara
constexpr int PIN_CS_TC2 = 13;     // TC2: salida del PTC
constexpr int PIN_SIS_RX = 16;     // UART2 <- SIS (su GPIO17)
constexpr int PIN_SIS_TX = 17;     // UART2 -> SIS (su GPIO16)
constexpr int PIN_HMI_RX = 35;     // UART1 <- HMI (su IO25)
constexpr int PIN_HMI_TX = 4;      // UART1 -> HMI (su IO32)
constexpr int PIN_LED = 2;         // LED de la placa

// ----------------------------- Tiempos de las tareas -------------------------
constexpr uint32_t CYCLE_PERIOD_MS = 10;    // tarea del ciclo
constexpr uint32_t TC_PERIOD_MS = 250;      // se lee un termopar cada 250 ms, alternando TC1 y TC2
constexpr uint32_t WATCHDOG_S = 2;          // reinicio si la tarea del ciclo se cuelga
constexpr uint32_t DOOR_DEBOUNCE_MS = 30;
constexpr uint8_t SENSOR_BAD_READS = 3;     // lecturas malas seguidas para dar un sensor por perdido

// ----------------------------- Perfiles --------------------------------------
// Valores de partida, a ajustar con ensayos (fase F9). El HMI sólo envía el
// número de calzado, intensidad y duración: las temperaturas y los minutos
// viven aquí.

// Temperatura objetivo del aire de la recámara (TC1), en °C
//                                       Suave  Media  Intensa
constexpr int16_t SETPOINT_C[4][3] = {
    /* 0 Cuero     */ {35, 40, 45},
    /* 1 Deportivo */ {40, 45, 50},
    /* 2 Bota      */ {40, 45, 50},
    /* 3 Sintético */ {38, 42, 48},
};

// Duración del tratamiento a temperatura, en minutos:  Corta  Media  Larga
constexpr uint32_t DURATION_MIN[3] = {5, 10, 25};

// ----------------------------- Regulación de temperatura ---------------------
// Etapa 1: histéresis sobre TC1. Las temperaturas van en décimas de grado (x10).
constexpr int16_t HYSTERESIS_X10 = 5;          // enciende por debajo de consigna − 0,5 °C; apaga por encima de + 0,5 °C
constexpr uint32_t HEATER_MIN_STATE_MS = 5000; // tiempo mínimo encendido o apagado (conmutación lenta del SSR)
constexpr int16_t TREAT_BAND_X10 = 30;         // "a temperatura" = TC1 a menos de 3 °C de la consigna
constexpr int16_t OVERTEMP_MARGIN_X10 = 50;    // TC1 más de 5 °C sobre la consigna = falla
constexpr int16_t TC2_MAX_X10 = 700;           // salida del PTC a más de 70 °C: se corta el calor... [POR MEDIR]
constexpr int16_t TC2_RESUME_X10 = 650;        // ...hasta que baje de 65 °C

// ----------------------------- Tiempos del ciclo -----------------------------
constexpr uint32_t SIS_BOOT_WAIT_MS = 5000;          // espera al SIS en el arranque
constexpr uint32_t PREHEAT_TIMEOUT_MS = 15 * 60000u; // sin llegar a temperatura = falla
constexpr uint32_t PAUSE_MAX_MS = 5 * 60000u;        // una pausa más larga cancela el ciclo
constexpr uint32_t CYCLE_MAX_MS = 120 * 60000u;      // tope global de un ciclo
constexpr uint32_t COOL_MAX_MS = 15 * 60000u;        // tope del enfriamiento

// ----------------------------- Enfriamiento y ventiladores -------------------
constexpr int16_t COOL_END_TC1_X10 = 350;      // el enfriamiento termina con TC1 < 35 °C...
constexpr int16_t COOL_END_TC2_X10 = 400;      // ...y TC2 < 40 °C
constexpr int16_t COLD_X10 = 350;              // en reposo, los ventiladores se apagan con TC2 < 35 °C...
constexpr uint32_t FAN_OFF_HOLD_MS = 60000;    // ...mantenido durante 1 min

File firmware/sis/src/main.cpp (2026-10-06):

// =============================================================================
//  QuitaSicote3000 — SIS (sistema de seguridad) · ESP32 DevKit V1
// =============================================================================
//  Este controlador hace SÓLO seguridad (ADR-0012). Decide tres relés:
//
//    RL1  permiso del PTC ............ sin él, el calefactor no puede encender
//    RL3  permiso de apagar FAN_P .... sin él, el ventilador del PTC sigue girando
//    RL4  forzar FAN_C ............... enciende el ventilador de circulación
//
//  No tiene termopar (ADR-0004): sus entradas son la puerta (contactos NA y NC)
//  y lo que informa el control. Lo que llega del control SÓLO PUEDE RESTRINGIR:
//  puede quitar el permiso o provocar un disparo, nunca conceder nada. Sin
//  temperatura, "frío" se estima por tiempo sin permiso del PTC.
//
//  Dos tareas de FreeRTOS:
//
//    taskSafety  cada 10 ms   puerta -> funciones de seguridad -> relés
//    taskLink    cada 10 ms   habla con el control y guarda en memoria
//
//  Las dos comparten las variables de la sección "Estado compartido", siempre
//  con el mutex tomado (ver la clase Lock).
// =============================================================================
#include <Arduino.h>
#include <Preferences.h>
#include <esp_task_wdt.h>

#include "config.h"
#include "qs_protocol.h"

using namespace qs;

// =============================================================================
//  Estado compartido entre las tareas
// =============================================================================

SemaphoreHandle_t stateMutex;

// Toma el mutex al crearse y lo suelta al salir del bloque:
//     { Lock lock;  ...leer o escribir el estado compartido...  }
struct Lock {
  Lock() { xSemaphoreTake(stateMutex, portMAX_DELAY); }
  ~Lock() { xSemaphoreGive(stateMutex); }
};

// --- Estado del SIS y sus salidas ---
SisState state = SisState::Boot;
uint16_t tripMask = 0;           // causas del disparo (bits TripBit)
Door door = Door::Invalid;
bool ptcPermit = false;          // RL1
bool fanPOffPermit = false;      // RL3
bool fanCForce = false;          // RL4

// --- Lo que informa el control (HB_CTRL) ---
bool heartbeatSeen = false;
uint32_t lastHeartbeatMs = 0;
uint8_t ctrlFlags = 0;           // bits CtrlFlag del último latido

// --- Temporizadores de la tarea de seguridad ---
uint32_t heatingMs = 0;          // tiempo acumulado con el permiso concedido (SIF-07)
uint32_t permitOffMs = 0;        // tiempo seguido con el permiso retirado

// --- Datos que sobreviven a un corte de energía (NVS) ---
uint8_t thermalEvents = 0;       // eventos térmicos ocurridos
uint16_t latchedTripMask = 0;    // disparo térmico pendiente de rearmar
bool lockout = false;            // equipo bloqueado
bool memoryInvalid = false;      // los datos guardados estaban corruptos
bool saveRequested = false;      // taskLink debe guardar

// --- Procedimiento de servicio (desbloqueo) ---
bool serviceActive = false;
uint32_t serviceStartMs = 0;
bool serviceDoorWasOpen = false;
uint8_t serviceDoorToggles = 0;

// Avisos para el control. La tarea de seguridad los encola; taskLink los envía.
QueueHandle_t eventQueue;

void emitEvent(uint8_t event, uint8_t detail = 0) {
  SisEventMsg message = {event, tripMask, detail};
  xQueueSend(eventQueue, &message, 0);  // si la cola está llena, se pierde: nunca se espera
}

// =============================================================================
//  Memoria no volátil
// =============================================================================
//  Un bloque de 8 bytes en NVS:  'S' 'Q' | versión | eventos | máscara (2) | bloqueo | CRC-8

constexpr size_t RECORD_SIZE = 8;

uint8_t crc8(const uint8_t* data, size_t len) {
  uint8_t crc = 0xFF;
  for (size_t i = 0; i < len; i++) {
    crc ^= data[i];
    for (int bit = 0; bit < 8; bit++) crc = (crc & 0x80) ? (crc << 1) ^ 0x31 : (crc << 1);
  }
  return crc;
}

// Se llama una vez en setup(), antes de crear las tareas.
void loadMemory() {
  Preferences nvs;
  nvs.begin("sis", true);
  uint8_t record[RECORD_SIZE];
  const size_t length = nvs.isKey("rec") ? nvs.getBytes("rec", record, sizeof(record)) : 0;
  nvs.end();

  if (length == 0) {  // equipo nuevo: nada guardado todavía
    saveRequested = true;
    return;
  }

  const bool good = length == RECORD_SIZE && record[0] == 'S' && record[1] == 'Q' &&
                    record[2] == 1 && record[6] <= 1 && crc8(record, 7) == record[7];
  if (!good) {
    // Datos corruptos: se arranca disparado y, por prudencia, se supone que ya
    // hubo un evento térmico (el siguiente bloquea).
    memoryInvalid = true;
    thermalEvents = 1;
    tripMask |= TRIP_MEMORY_INVALID;
    return;
  }

  thermalEvents = record[3];
  latchedTripMask = record[4] | (record[5] << 8);
  lockout = record[6] == 1;

  // Lo que estaba enclavado antes del corte sigue enclavado.
  if (latchedTripMask != 0 || lockout) tripMask |= latchedTripMask | TRIP_FROM_MEMORY;
  if (lockout) state = SisState::Locked;
}
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

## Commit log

2026-10-01 Definir arquitectura y estructura inicial del proyecto
    Estructura de carpetas (docs, hardware, firmware, tools, datos) y documentacion:
    requisitos, arquitectura (Mega control, Nano SIS, ESP32 HMI), seguridad,
    plan de pruebas y ADRs 0001-0007.
2026-10-01 Refinar arquitectura: potencia, perfiles, termostato, ventiladores y puerta
    - Alimentacion 12 V/20 A, PTC 100 W, ventiladores y camara de circuitos
    - Perfiles de tratamiento por opciones discretas (4 calzados x 3 x 3)
    - ADR-0006 a 0009: producto domestico, perfiles, termostato con rearme
    automatico (enclavado en EEPROM) y ventilador del PTC por rele (NC, nivel alto)
    - Limit switch con contactos NA y NC; inicio solo con puerta cerrada
    - Pausa maxima de 5 min
2026-10-01 Plan maestro, pinout por controlador y depuración de la documentación
    - Documentación centrada en el software; se eliminan hardware/, datos/,
    tools/ y documentos sólo de hardware. Docs de cada firmware junto a su código
    - docs/PLAN-MAESTRO.md: plan completo de electrónica y firmware (protocolo
    byte a byte, SIS, control, fases F0-F10, parámetros, riesgos)
    - docs/pinout/: pinout independiente para Mega, Nano y ESP32 del HMI
    - firmware/hmi/PLAN.md: plan de la interfaz LVGL en horizontal
    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
2026-10-01 Plan maestro v5: control en ESP32-S3, SIS en ESP32 Dev Kit
    - Regla de máxima prioridad: control y SIS en controladores separados
    (ADR-0012), ahora ESP32-S3 y ESP32 Dev Kit (ADR-0002)
    - Sólo módulos y dispositivos (ADR-0013): lógica AND/OR con contactos de
    relé (RL2/RL3 y SSR2/RL4); sin optoacopladores, convertidores de nivel
    ni fusibles
    - Relé de permiso del PTC como módulo en serie (ADR-0010)
    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
2026-10-06 Firmware inicial con FreeRTOS; control y SIS en ESP32 DevKit V1
    - Control y SIS pasan a un ESP32 DevKit V1 cada uno: pinout nuevo del
    control y documentación actualizada (plan maestro v7, ADR-0012).
    - Primera versión del firmware de los tres nodos, con toda la lógica en
    tareas de FreeRTOS y pocos archivos: un main.cpp y un config.h por nodo.
    - Protocolo común en un solo archivo: firmware/compartido/qs_protocol.h.
    Los tres proyectos compilan; sin probar todavía en hardware.
2026-10-06 Solo 2 termocuplas: el SIS queda sin termocupla
    TC1 y TC2 quedan en el control. Se retiran SIF-01/03/04/08 del SIS;
    "frio" se estima por tiempo (10 min sin permiso del PTC). HB_SIS pasa
    a 7 bytes. ADR-0004 y documentacion derivada actualizados.
2026-10-08 HMI: interfaz usable sin conexión, indicador de enlace y duraciones 5/10/25 min
    - Sin enlace con el control el asistente sigue completo; INICIAR y demás
    solicitudes muestran un aviso de error en vez de enviarse.
    - Punto de conexión arriba a la derecha (verde/rojo) en todas las pantallas.
    - La pantalla de duración muestra los minutos de cada opción.
    - Duraciones: corta 5 min, media 10 min, larga 25 min (control, HMI y docs).
    - Panel con colores invertidos (invert = true).
    [config.h, display.h, ui.cpp]
2026-10-08 Guía de conexión paso a paso y diagrama de Fritzing
    Guía para armar el equipo por primera vez, con el diagrama de Fritzing
    en alta resolución, recortes por zonas, comprobaciones y encendido por etapas.
    [QuitaSicote3000_conexiones.fzz]
2026-10-08 Guía de conexión: versión corta y tablas de pinouts
